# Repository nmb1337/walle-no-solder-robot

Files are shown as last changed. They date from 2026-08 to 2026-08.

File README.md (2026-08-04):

# WALL-E no-solder robot gateway

An A1-sized, PETG-printed WALL-E-style robot with two differential-drive
wheels, six positional joints, ESP32-S3 camera/audio hardware, and a Windows
LAN gateway for API-based text and image intelligence.

This is an original parameterised chassis. It is visually inspired by WALL-E
and studies of public community projects, but it does not redistribute or copy
another creator's STL files.

## Read these first

1. [Design dimensions and strict fit rules](DESIGN_FREEZE.md)
2. [No-solder bill of materials](docs/BOM.md)
3. [Assembly guide](docs/ASSEMBLY.md)
4. [Engineering validation and release gates](docs/VALIDATION.md)
5. [PETG / AMS Lite setup](shopping/ams-lite-setup.md)

The project is intentionally blocked from full-shell printing until the five
fit parts pass with the bought hardware. This prevents a wrong wheel bore,
battery pack, motor shaft or camera connector from turning into a large failed
print.

## Software

Run the local gateway with `start-gateway.ps1`. It serves the dashboard on
`http://127.0.0.1:8100` and exposes API-compatible text, image, motion, camera
and optional STT/TTS routes. API keys stay only in `gateway-config.json`, which
is not included in the project package.

The motor ESP32 polls the gateway for movement and joint events. It has a
one-second motor watchdog and starts stopped. See `firmware/README.md` before
connecting any battery.

## Print source

The source is `cad/walle_parametric.scad`; rendered V2 parts are in
`cad/stl_v2/`. Every V2 STL has been checked against the Bambu Lab A1
`256 x 256 x 256 mm` build volume. Print PETG fit parts first, then proceed in
the order in `docs/ASSEMBLY.md`.

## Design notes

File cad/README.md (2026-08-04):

# WALL-E v2 printable parts

`walle_parametric.scad` is the source of truth for the no-solder v2 design.
It targets a two-wheel, WALL-E-style robot built around bought 42 mm rubber
wheels, N20 motors, MG90S servos, a Waveshare ESP32-S3-AUDIO-Board and an
OV2640 camera board.

The current V2 exports are in `stl_v2/`. Every part stays below the Bambu A1
`256 x 256 x 256 mm` build volume. The previous `stl/` directory and its
CoreS3 tray are superseded and must not be sent to print.

## First fit prints

1. `walle_n20_motor_clamp.stl` x2
2. `walle_battery_tray.stl` x1
3. `walle_audio_core_cradle.stl` x1
4. `walle_ov2640_camera_mount.stl` x1
5. `walle_mg90s_horn_adapter.stl` x6
6. `walle_ball_caster_plate.stl` x1
7. `walle_base_plate.stl` x1

Use PETG at 0.20 mm layer height, 4 walls, and 30% gyroid infill for structural
parts. Print the body, head and cosmetic track covers only after these parts
fit the bought hardware. Full dimensions and strict buying rules are in
`../DESIGN_FREEZE.md`; use `../docs/ASSEMBLY.md` and
`../docs/VALIDATION.md` for the assembly and release gates.

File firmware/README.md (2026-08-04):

# Motion controller

`esp32_walle_controller.ino` runs on the pre-soldered ESP32 DevKitC V4. It
polls the Windows gateway every 250 ms, drives a TB6612FNG motor driver and a
PCA9685 servo board, and stops both motors after one second without a command.

## Exact connections

| ESP32 pin | TB6612FNG |
| --- | --- |
| GPIO 25 | AIN1 |
| GPIO 26 | AIN2 |
| GPIO 27 | PWMA |
| GPIO 32 | BIN1 |
| GPIO 33 | BIN2 |
| GPIO 14 | PWMB |
| GPIO 13 | STBY |
| 3.3 V | VCC |
| GND | GND |

PCA9685: ESP32 `GPIO 21 -> SDA`, `GPIO 22 -> SCL`, common GND, and a separate
regulated `5 V / 8 A or higher` rail on its servo power terminal. Motors use
the protected 2S battery at `VM`; the ESP32 and PCA9685 must share GND with
that battery but never draw servo current through the ESP32 USB port.

The sketch supports Arduino-ESP32 2.x and 3.x LEDC APIs. Gateway events use
ASCII values (`left`, `right`, `center`, `up`, `down`, `raise`, `stow`) so the
firmware is not affected by serial or source-file Chinese encoding.

Before fitting wheels or arms, power the controller from USB, verify all six
servo directions, then test each motor with the robot raised off the table.

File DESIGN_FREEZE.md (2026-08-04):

# WALL-E v2 design freeze

This is a no-solder, two-wheel WALL-E-style robot. It is intentionally not a
copy of the MakerWorld model. The MakerWorld page attributes its design to
other work under CC BY-NC-SA and its current print profile is not public, so
this project only uses it as visual and assembly reference.

## Mechanical envelope

All dimensions are millimetres. The source of truth is
`cad/walle_parametric.scad`.

| Printed / bought item | Frozen dimensions | Fit rule |
| --- | --- | --- |
| Base plate | 178 x 112 x 5 | Four M3 holes and battery straps |
| Body shell | 184 x 118 x 100 | Upper opening for service |
| Head shell | 182 x 90 x 76 | Front panel is removable |
| Face panel | 174 x 5 x 70 | Two 40 mm eye openings |
| Complete body, wheels included | about 240 wide x 118 deep x 184 high | Fits the A1 in separate parts |
| Drive wheels, bought | 42 diameter x 19 wide | 3 mm D-bore only, not round bore |
| N20 motor | 10 x 12 x 34-36 body, 3 mm D shaft, 6 V, 100 RPM | Must be pre-wired with a 2-pin connector |
| Motor clamp cavity | 38.5 x 13.4 x 11.4 | Cable tie slots; do not substitute a 25GA/370 motor |
| Battery tray internal envelope | 82 x 48 x 24 | Real pack must be no larger than 80 x 46 x 22 |
| MG90S servo envelope | 22.8 x 12.2 x 28.5 | Six 180-degree metal-gear units |
| ESP32-S3 audio board | 58 mm round board | 0.8 mm clearance in the printed cradle |
| OV2640 camera board | 35.7 x 23.9 | 24-pin 0.5 mm FPC version for the audio board |

The outer decorative side covers make the two-wheel chassis look like WALL-E
tracks. They are not load-bearing tracks. This is deliberate: two purchased
rubber wheels are quieter, easier to assemble, and reliable on tile and wood.

## Buy exactly these specifications

1. `Waveshare ESP32-S3-AUDIO-Board`, standard version, with dual microphone
   array, speaker header and 24-pin DVP camera connector. Do not buy an
   ESP32-S3-WROOM module alone: it needs soldering and has no ready audio path.
2. Compatible `OV2640 Camera Board`, `35.7 x 23.9 mm`, 24-pin, 0.5 mm FPC.
3. `ESP32 DevKitC V4`, USB-C and pre-soldered headers, for motors and servos.
4. Two `N20 6V 100 RPM` motors, `3 mm D shaft`, 10 x 12 x 34-36 mm. Buy the
   pre-wired 1.25 mm 2-pin version, plus one spare motor.
5. Two `42 x 19 mm` rubber robot wheels with a `3 mm D-bore`, not foam wheels
   and not a 2 mm or round bore wheel. This replaces TPU entirely.
6. `TB6612FNG` dual motor driver with pre-soldered signal header and screw
   terminals. It must have an accessible `STBY` pin.
7. `PCA9685` 16-channel servo board with pre-soldered headers.
8. Seven `MG90S 180-degree metal-gear` servos: six fitted, one spare. SG90,
   360-degree servos and 2 g aircraft servos are not compatible with this
   articulated design.
9. Protected `2S 7.4 V` Li-ion pack, maximum `80 x 46 x 22 mm`, with XT30
   output and an 8.4 V charger explicitly sold for that pack. Do not buy a
   18650 holder or a bare 18650 pack.
10. Fixed `5 V 10 A` buck converter with screw terminals for servos, ESP32
    DevKitC and the audio board. A 3 A converter is unsafe for six MG90S servos.
11. Fixed `6.0 V / 3 A` buck converter with screw terminals for TB6612 `VM`
    and the N20 motors. Do not connect a 2S battery directly to 6 V motors.
12. XT30 pre-made pigtail, 5 A inline fuse holder, 5 A fuse, 20 cm pre-crimped
    Dupont leads, and an M3 screw/standoff box. No stripping or soldering is
    required if every cable is bought pre-made.

The Taobao candidate [42 mm solid rubber N20 wheel](https://item.taobao.com/item.htm?id=657052441273)
does explicitly state `42 mm`, N20 compatibility and a `3 mm D-bore`. Its
page does not state wheel width, so ask the seller to confirm `19 mm or less`
before adding it to the cart. Do not substitute a different wheel just because
its title also says "N20".

## PETG and AMS Lite

Use PETG for every printed structural part. Do not put TPU in the AMS Lite.
If you have two PETG colours, load yellow in A and black in B. If you only
have one PETG spool, load it in A and print all parts in that material; colour
does not affect fitting. The bought rubber wheels provide grip.

Print and dry-fit before any large shell:

1. `cad/stl_v2/walle_n20_motor_clamp.stl`
2. One bought wheel and the motor shaft
3. `cad/stl_v2/walle_battery_tray.stl` with the real battery
4. `cad/stl_v2/walle_audio_core_cradle.stl` with the real ESP32-S3 board
5. `cad/stl_v2/walle_ov2640_camera_mount.stl` with the camera and FPC cable

The body and head are printed only after those five dry-fits pass. Also dry-fit
the MG90S horn adapter and rear ball-caster plate. The battery tray, motor
clamp, caster plate and horn adapter must be re-exported if a seller changes a
quoted physical dimension.

## Functional boundary

The gateway supports provider switching, text chat, image analysis, movement
and the standard OpenAI-compatible STT/TTS routes. The hardware is designed
for head yaw/pitch, two arms with shoulder/elbow joints, and two-wheel
movement. AI requests stay on the configured API, not on the 8100T.

Music playback must use a service and account that authorises playback. The
project will not promise access to an arbitrary percentage of copyrighted
catalogues or bypass a platform's controls.

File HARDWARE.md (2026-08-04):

# Hardware overview

Use [docs/BOM.md](docs/BOM.md) for the complete procurement specification and
[docs/ASSEMBLY.md](docs/ASSEMBLY.md) for the no-solder harness order.

The architecture has two controllers:

- ESP32 DevKitC V4 -> TB6612FNG -> two 6 V N20 motors and PCA9685 -> six
  MG90S 180-degree servos.
- Waveshare ESP32-S3-AUDIO-Board + OV2640 + 4 ohm speaker -> Wi-Fi voice and
  camera client for the Windows gateway.

Power starts at a fused 2S LiPo XT30 output. It splits into a `6.0 V / 3 A`
motor rail and an isolated `5 V / 10 A` servo/logic rail, with all grounds
common. The ESP32-S3 audio board receives the 5 V logic rail through USB-C.
No 6 V motor rail may enter an ESP32, PCA9685 logic pin or servo connector.

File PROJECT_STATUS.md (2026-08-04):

# Project status

## Completed

- Windows gateway with API profile storage that excludes secrets from source.
- Text and image relay support, dashboard movement controls and a one-second
  motion watchdog in the ESP32 controller.
- Original V2 OpenSCAD source and A1-bounded STL exports.
- No-solder BOM, PETG print guide, assembly guide and engineering validation.
- Static checks: gateway Python syntax, action translation, and V2 STL bounds.

## Required before full build

- Seller confirms motor shaft, wheel width/bore, battery dimensions and motor
  stall current against `docs/BOM.md`.
- Fit prints pass with real motor, wheel, battery, audio board, camera,
  supplied servo horn and ball caster.
- Regulated rails measure exactly 5.0 V and 6.0 V before electronics connect.
- Bench-test motors, six servos, watchdog, camera upload and API image call.

No purchase, order, payment, or printer job is submitted by this repository.

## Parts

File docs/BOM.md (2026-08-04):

# No-solder BOM

Buy by the **specification column**, not only by the title. A listing with a
different shaft, plug, voltage, or physical size is not a compatible
substitute. Prices change often, so this list intentionally avoids promising
one seller or one price.

## Motion and structure

| Qty | Exact specification | Maximum envelope / interface | Search words |
| --- | --- | --- | --- |
| 3 | N20 metal gearmotor, 6 V, 100 RPM, 3 mm D shaft, 10 x 12 x 34-36 mm | Stall current <= 0.8 A; pre-wired MX1.25 2P lead; two fitted + one spare | `N20 6V 100转 3mm D轴 带线 1.25` |
| 2 | Solid rubber wheel, 42 mm OD, <= 19 mm width, 3 mm D-bore | No foam, no round bore, no 2 mm shaft version | `42mm 橡胶实心轮 N20 3mm D孔` |
| 7 | MG90S metal-gear, 180 degree servo | 22.8 x 12.2 x 28.5 mm; six fitted + one spare | `MG90S 金属齿 180度` |
| 1 | 15 mm ball caster, complete assembly | body <= 20 x 20 x 16 mm; M2 mounting pattern must be shown | `15mm 万向滚球 小车` |
| 1 | M2 screw/nut kit | M2 x 6 and M2 x 8 for supplied servo horns | `M2 螺丝螺母盒` |
| 1 | M3 screw/standoff kit | M3 x 8/10/12/14/16 and M3 nuts | `M3 铜柱螺丝盒` |

## Electronics

| Qty | Exact specification | Required detail-page evidence | Search words |
| --- | --- | --- | --- |
| 1 | Waveshare ESP32-S3-AUDIO-Board, standard board | 58 mm round board; dual microphones, 24-pin DVP camera connector, speaker header | `微雪 ESP32-S3 AUDIO Board` |
| 1 | OV2640 camera board, 24-pin, 0.5 mm FPC | 35.7 x 23.9 mm; connector orientation matches the audio board | `OV2640 24P 0.5mm FPC 微雪` |
| 1 | 4 ohm / 3 W speaker with pre-crimped 1.25 mm 2P plug | 40 mm maximum diameter, connector already fitted | `4欧3W 喇叭 1.25 2P 带线` |
| 1 | ESP32 DevKitC V4 | USB-C and pre-soldered headers | `ESP32 DevKitC V4 已焊排针 Type-C` |
| 1 | TB6612FNG motor-driver board | pre-soldered signal header, screw terminals, STBY exposed | `TB6612FNG 端子 已焊排针` |
| 1 | PCA9685 16-channel servo board | pre-soldered header and separate servo power terminal | `PCA9685 已焊排针 舵机板` |
| 1 | USB-A to USB-C power lead | 20-30 cm, rated 3 A or above | `USB A 转 Type C 20cm 3A` |

## Power and pre-made wiring

| Qty | Exact specification | Why it is required |
| --- | --- | --- |
| 1 | 2S 7.4 V, 1500 mAh or higher, >= 20C LiPo soft pack, XT30 output, <= 80 x 46 x 22 mm | Fits the printed tray and supplies the simultaneous servo/motor peak. |
| 1 | Matched 2S balance charger for that pack | Never charge a 2S LiPo from a 5 V USB charger. |
| 1 | 5 V / 10 A fixed buck converter, screw terminals | Feeds PCA9685 servo rail, ESP32 DevKitC and the audio board through USB-C. 3 A is not sufficient. |
| 1 | 6.0 V / 3 A fixed buck converter, screw terminals | Feeds only TB6612 `VM` and the two N20 motors. A 2S pack must not be connected directly to 6 V motors. |
| 1 | XT30 pre-made pigtail to stripped/tinned wire, 20 cm | Connects the battery to the fused power split without soldering. |
| 1 | 5 A inline automotive-style fuse holder and 5 A fuse | In series with battery positive before both buck converters. |
| 1 | Pre-crimped Dupont kit, 20 cm, male-to-female and female-to-female | For ESP32, PCA9685 and TB6612 signals. |
| 1 | WAGO 221-412 lever connectors, or a small screw-terminal power distribution block | Makes the battery/buck ground common without soldering. |

## Do not buy

- CoreS3, standalone ESP32-S3-WROOM modules, bare PCBs, or boards requiring
  header soldering.
- SG90 continuous rotation servos, 2 g aircraft servos, or MG90S 360-degree
  versions. They cannot position the head and arms.
- 18650 holders, unprotected loose cells, a 3 A 5 V buck, or an N20 motor
  marked 300 RPM or 12 V.
- TPU filament. The purchased rubber wheels are the correct tyre material.

## Seller confirmation message

Send this exact question to a seller when a dimension is not on the page:

> 请确认这款 N20 电机为 6V、100RPM、3mm D 型输出轴，电机本体 10x12mm、总长 34-36mm、轴长至少 9mm，并且堵转电流不超过 0.8A。请确认轮子外径 42mm、宽度不超过 19mm、孔为 3mm D 孔。请提供实物尺寸图。

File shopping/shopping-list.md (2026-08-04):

# Purchasing status

The old CoreS3, 70 mm wheel, PLA and 5 V / 3 A shopping list is obsolete. Do
not add or purchase from it.

The authoritative no-solder purchase list, exact dimensions, quantity, search
words and seller-confirmation message are in [../docs/BOM.md](../docs/BOM.md).
The V2 design needs two separate regulated rails: `5 V / 10 A` for servos and
logic, and `6.0 V / 3 A` for the 6 V N20 motors.

The Taobao cart is intentionally not treated as verified. Before any item is
added, compare its product page with `docs/BOM.md`, especially the wheel bore
and width, motor stall current, real battery dimensions and all pre-crimped
connectors.

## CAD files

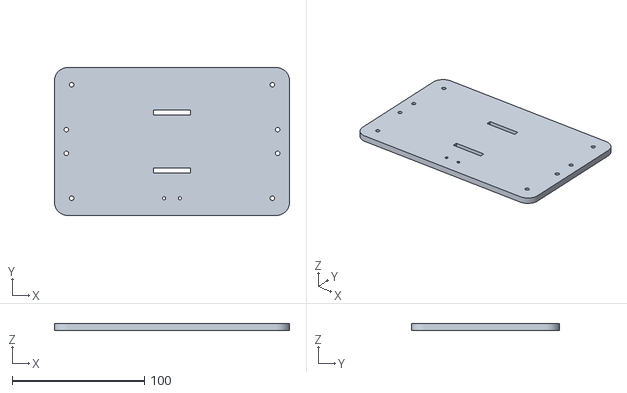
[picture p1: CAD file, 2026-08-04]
cad/stl_v2/walle_base_plate.stl
178.0 x 112.0 x 5.00

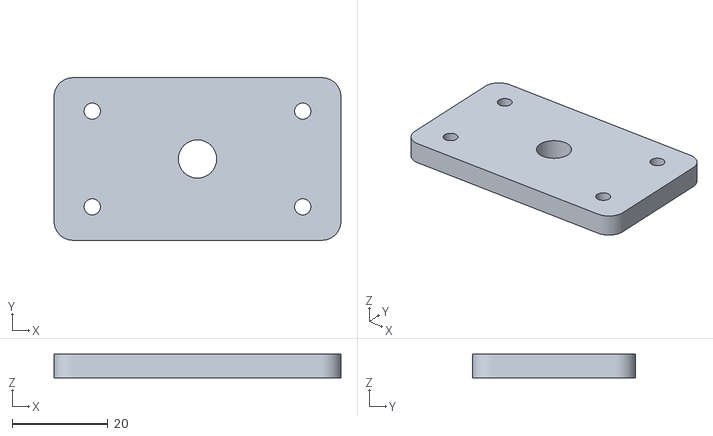
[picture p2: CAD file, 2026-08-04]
cad/stl_v2/walle_head_servo_adapter.stl
60.0 x 34.0 x 5.00

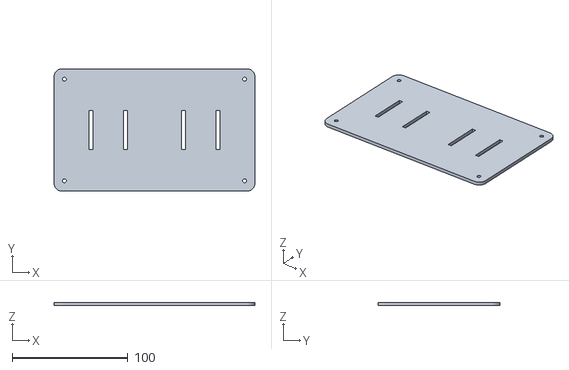
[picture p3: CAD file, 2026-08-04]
cad/stl_v2/walle_electronics_deck.stl
174.0 x 106.0 x 3.00

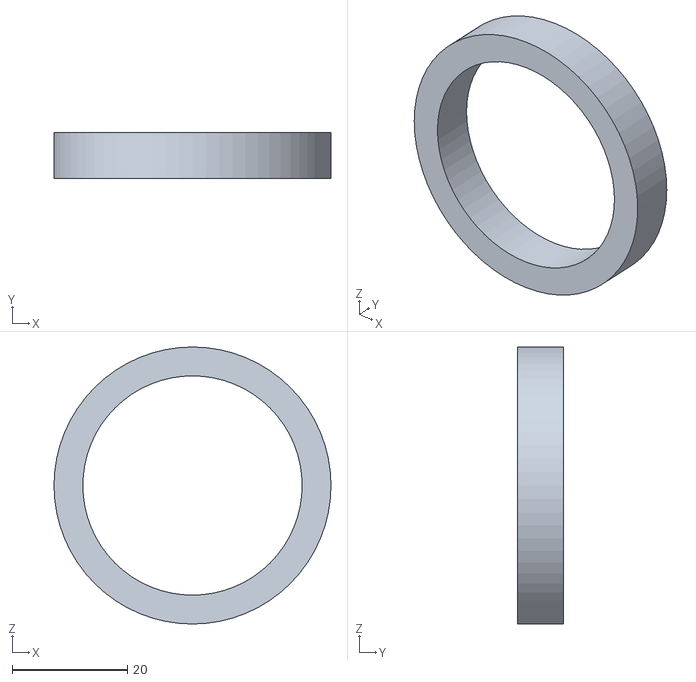
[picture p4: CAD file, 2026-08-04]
cad/stl_v2/walle_eye_ring.stl
48.0 x 8.00 x 48.0

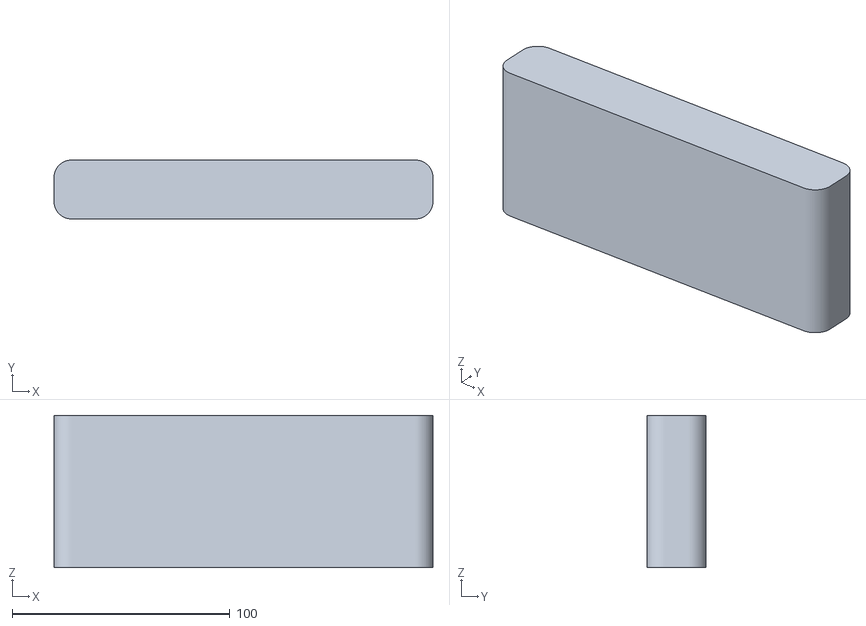
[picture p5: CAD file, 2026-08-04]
cad/stl_v2/walle_face_plate.stl
174.0 x 27.0 x 70.0

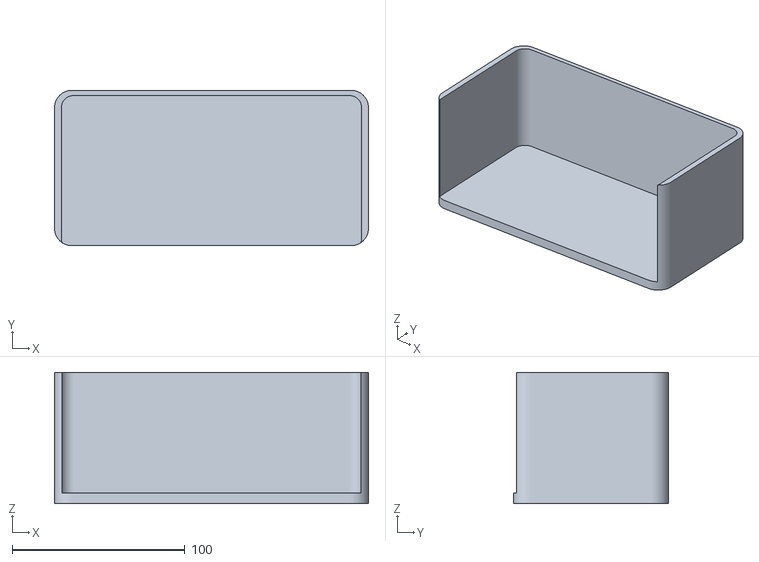
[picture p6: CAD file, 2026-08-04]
cad/stl_v2/walle_head_shell.stl
182.0 x 90.0 x 76.0

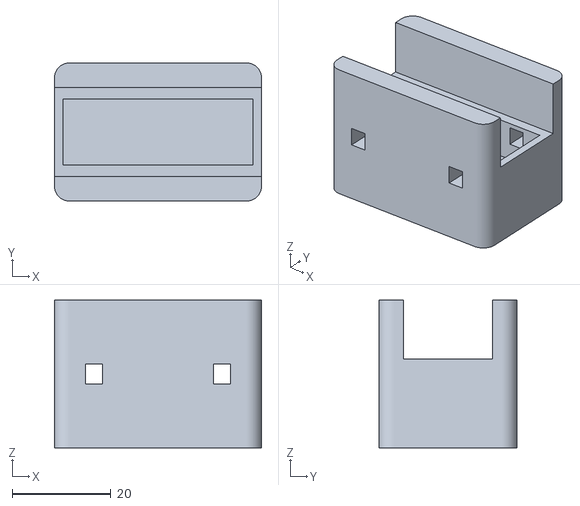
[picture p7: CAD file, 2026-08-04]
cad/stl_v2/walle_n20_motor_clamp.stl
42.0 x 28.0 x 30.0

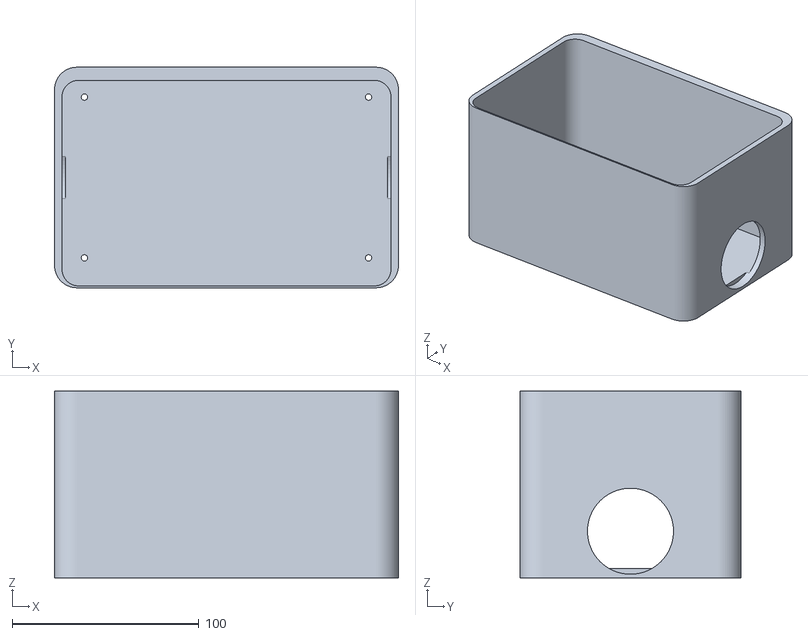
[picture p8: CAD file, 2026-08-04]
cad/stl_v2/walle_body_shell.stl
184.0 x 118.0 x 100.0

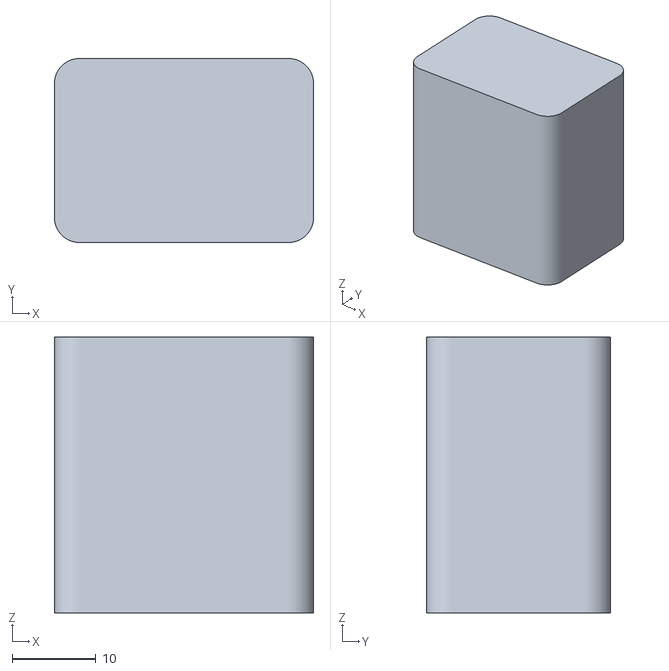
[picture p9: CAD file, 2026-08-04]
cad/stl_v2/walle_mg90s_servo_cradle.stl
31.0 x 22.0 x 33.0

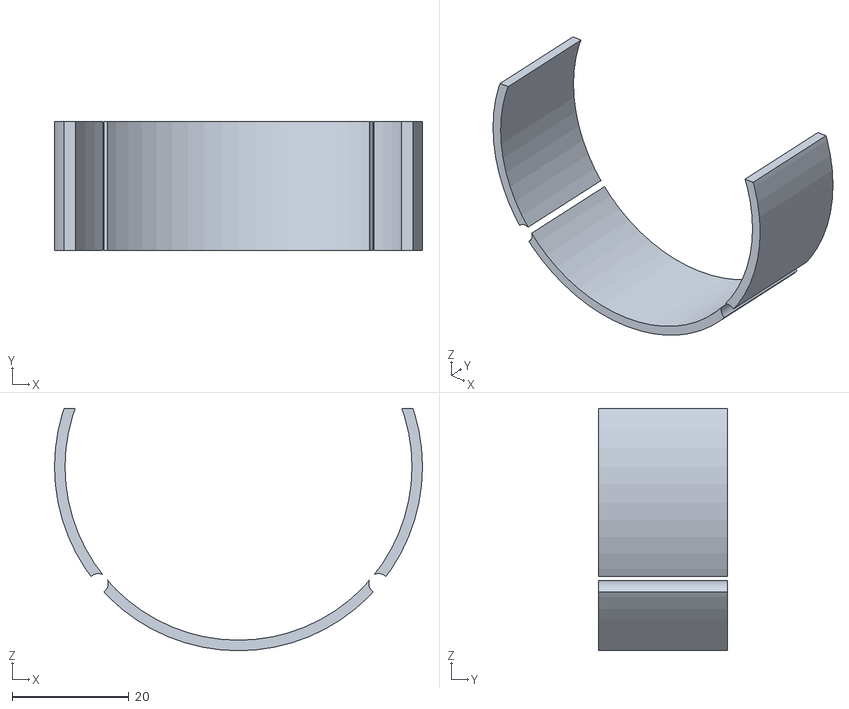
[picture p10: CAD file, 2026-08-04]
cad/stl_v2/walle_audio_core_cradle.stl
63.0 x 22.0 x 41.5

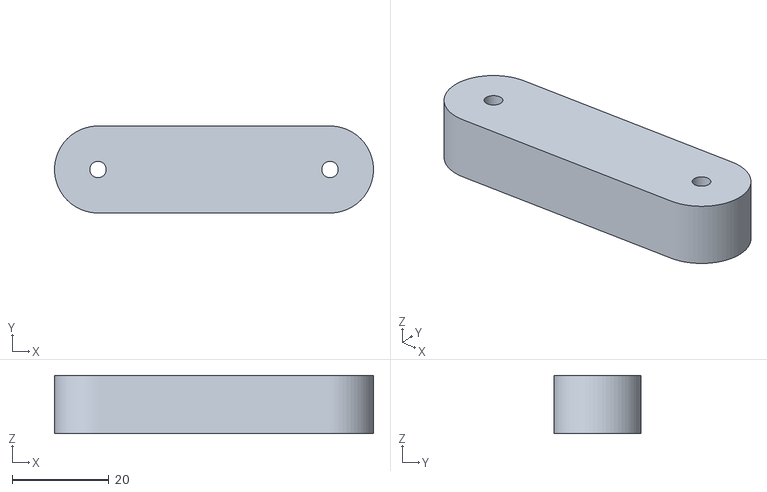
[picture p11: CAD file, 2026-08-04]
cad/stl_v2/walle_arm_link_upper.stl
66.0 x 18.0 x 12.0

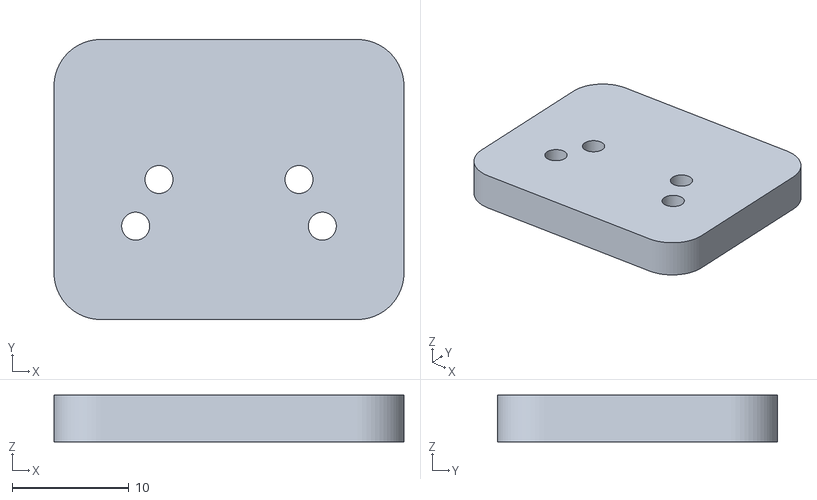
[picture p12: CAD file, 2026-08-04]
cad/stl_v2/walle_ball_caster_plate.stl
30.0 x 24.0 x 4.00

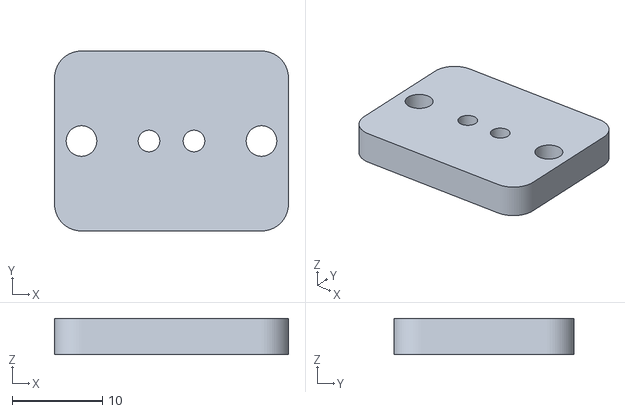
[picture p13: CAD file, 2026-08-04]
cad/stl_v2/walle_mg90s_horn_adapter.stl
26.0 x 20.0 x 4.00

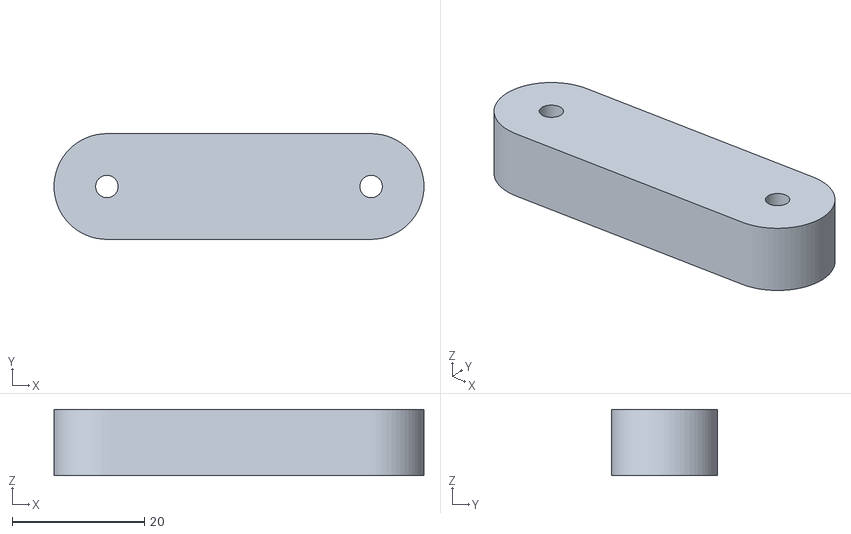
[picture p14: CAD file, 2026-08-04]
cad/stl_v2/walle_arm_link_lower.stl
56.0 x 16.0 x 10.0

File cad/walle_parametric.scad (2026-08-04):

// WALLE no-solder medium robot, millimetres.
// Target hardware: 42 mm N20 rubber wheels, MG90S 180-degree servos,
// Waveshare ESP32-S3-AUDIO-Board (diameter 58 mm, height 48.8 mm),
// and a 24-pin OV2640 camera module. Every printed part fits a Bambu A1.

$fn = 64;

body_w = 184;
body_d = 118;
body_h = 100;
head_w = 182;
head_d = 90;
head_h = 76;
wall = 3;
clearance = 0.8;

drive_wheel_d = 42;
drive_wheel_w = 19;
drive_axle_d = 3;               // N20 3 mm D-shaft
wheel_center_z = drive_wheel_d / 2 + 4;

mg90s_w = 22.8;
mg90s_d = 12.2;
mg90s_h = 28.5;

audio_core_d = 58;
audio_core_h = 48.8;
camera_pcb_w = 35.7;            // Waveshare OV2640 Camera Board
camera_pcb_h = 23.9;            // 24-pin, 0.5 mm FPC connector

// 2S 1800 mAh pack envelope. Smaller packs use foam and hook-and-loop strap.
battery_bay_w = 82;
battery_bay_d = 48;
battery_bay_h = 24;

part = "assembly_preview";

module rounded_box(w, d, h, r = 8) {
    linear_extrude(height = h, center = true)
        hull()
            for (x = [-w / 2 + r, w / 2 - r])
                for (y = [-d / 2 + r, d / 2 - r])
                    translate([x, y]) circle(r = r);
}

module m3_hole(h = 20) { cylinder(d = 3.4, h = h, center = true); }
module m2_hole(h = 20) { cylinder(d = 2.4, h = h, center = true); }

module base_plate() {
    difference() {
        rounded_box(178, 112, 5, 10);
        for (x = [-76, 76], y = [-43, 43])
            translate([x, y, 0]) m3_hole();
        // N20 motor-clamp pairs. Clamp centres are x = +/-80, y = 0.
        for (x = [-80, 80], y = [-9, 9])
            translate([x, y, 0]) m3_hole();
        // Rear ball-caster plate. M2 slots allow small seller variations.
        for (x = [-6, 6])
            translate([x, -43, 0]) m2_hole();
        // Hook-and-loop slots for battery and cable restraint.
        for (y = [-22, 22])
            translate([0, y, 0]) cube([28, 4, 10], center = true);
    }
}

module body_shell() {
    difference() {
        translate([0, 0, body_h / 2]) rounded_box(body_w, body_d, body_h, 12);
        // Open top, 6 mm bottom, 4 mm rear wall. Electronics insert from above.
        translate([0, -3, body_h / 2 + 5]) rounded_box(body_w - 8, body_d - 8, body_h, 9);
        // Clearance for two real 42 mm rubber wheels.
        for (side = [-1, 1])
            translate([side * (body_w / 2 + 2), 0, wheel_center_z])
                rotate([0, 90, 0]) cylinder(d = drive_wheel_d + 4, h = 16, center = true);
        // Match the base plate's four M3 body-fastening holes.
        for (x = [-76, 76], y = [-43, 43])
            translate([x, y, 3]) m3_hole(16);
    }
}

// Cosmetic side cover: it creates the WALL-E tracked appearance while the
// bought rubber wheel remains exposed through the 46 mm opening.
module track_cover() {
    difference() {
        rotate([0, 90, 0])
            linear_extrude(height = 5, center = true)
                difference() {
                    hull() {
                        translate([0, -32]) circle(d = 58);
                        translate([0, 32]) circle(d = 58);
                    }
                    circle(d = drive_wheel_d + 4);
                }
        // Two M3 mounting holes along the long axis.
        for (y = [-43, 43])
            translate([0, y, 0]) rotate([0, 90, 0]) m3_hole(12);
    }
}

module n20_motor_clamp() {
    difference() {
        rounded_box(42, 28, 30, 3);
        // N20 motor body and gearbox, axis along X. Use two small cable ties.
        cube([38.5, 13.4, 11.4], center = true);
        translate([0, 0, 9]) cube([44, 18, 12], center = true);
        for (x = [-13, 13])
            translate([x, 0, 0]) cube([3.5, 32, 4], center = true);
        for (y = [-9, 9])
            translate([0, y, -10]) m3_hole(8);
    }
}

module battery_tray() {
    difference() {
        rounded_box(battery_bay_w + 8, battery_bay_d + 8, battery_bay_h + 6, 5);
        translate([0, 0, 3]) rounded_box(battery_bay_w, battery_bay_d, battery_bay_h + 8, 3);
        for (y = [-15, 15])
            translate([0, y, 0]) cube([32, 4, 40], center = true);
    }
}

module electronics_deck() {
    difference() {
        rounded_box(174, 106, 3, 7);
        for (x = [-78, 78], y = [-44, 44])
            translate([x, y, 0]) m3_hole();
        // Universal tie-down slots instead of vendor-specific hole patterns.
        for (x = [-55, -25, 25, 55])
            translate([x, 0, 0]) cube([3.5, 34, 10], center = true);
    }
}

module head_shell() {
    difference() {
        translate([0, 0, head_h / 2]) rounded_box(head_w, head_d, head_h, 10);
        // Face is a separate panel; this leaves the front open for service.
        translate([0, -3, head_h / 2 + 3]) rounded_box(head_w - 8, head_d, head_h - 6, 7);
    }
}

module face_plate() {
    difference() {
        translate([0, 0, 36]) rounded_box(174, 5, 70, 8);
        for (x = [-44, 44])
            translate([x, 0, 43]) rotate([90, 0, 0]) cylinder(d = 40, h = 12, center = true);
        // Speaker grille: three rows of 4 mm holes below the eyes.
        for (x = [-24 : 8 : 24], z = [10 : 8 : 26])
            translate([x, 0, z]) rotate([90, 0, 0]) cylinder(d = 4, h = 12, center = true);
        for (x = [-76, 76])
            translate([x, 0, 8]) rotate([90, 0, 0]) m3_hole(12);
    }
}

module eye_ring() {
    difference() {
        rotate([90, 0, 0]) cylinder(d = 48, h = 8, center = true);
        rotate([90, 0, 0]) cylinder(d = 38, h = 12, center = true);
    }
}

// Holds the 35.7 x 23.9 mm OV2640 board behind one eye. It deliberately has
// generous clearance for the 24-pin FPC cable and works with a small foam pad.
module ov2640_camera_mount() {
    difference() {
        rounded_box(46, 8, 34, 3);
        cube([camera_pcb_w + 1.2, 12, camera_pcb_h + 1.2], center = true);
        rotate([90, 0, 0]) cylinder(d = 12, h = 14, center = true);
        for (x = [-18, 18])
            translate([x, 0, -12]) rotate([90, 0, 0]) m3_hole(14);
    }
}

// Cradle for Waveshare ESP32-S3-AUDIO-Board: official envelope is 58 mm x 48.8 mm.
module audio_core_cradle() {
    difference() {
        rotate([90, 0, 0]) cylinder(d = audio_core_d + 5, h = 22, center = true);
        rotate([90, 0, 0]) cylinder(d = audio_core_d + 1.4, h = 26, center = true);
        // Open the upper third so the board can be inserted without force.
        translate([0, 0, 25]) cube([80, 30, 30], center = true);
        for (x = [-24, 24])
            translate([x, 0, -20]) rotate([90, 0, 0]) m3_hole(30);
    }
}

module mg90s_servo_cradle() {
    difference() {
        rounded_box(31, 22, 33, 3);
        translate([0, 0, 1]) cube([mg90s_w + 0.9, mg90s_d + 0.9, mg90s_h + 1], center = true);
        for (x = [-12, 12])
            translate([x, 0, -12]) m3_hole(8);
    }
}

module shoulder_mount() {
    difference() {
        rounded_box(40, 30, 38, 4);
        translate([0, 0, 1]) cube([mg90s_w + 1, mg90s_d + 1, mg90s_h + 2], center = true);
        rotate([90, 0, 0]) cylinder(d = 8, h = 40, center = true);
        for (x = [-15, 15]) translate([x, 0, -14]) m3_hole(10);
    }
}

module arm_link_upper() {
    difference() {
        hull() {
            translate([-24, 0, 0]) cylinder(d = 18, h = 12, center = true);
            translate([24, 0, 0]) cylinder(d = 18, h = 12, center = true);
        }
        for (x = [-24, 24]) translate([x, 0, 0]) cylinder(d = 3.4, h = 20, center = true);
    }
}

module arm_link_lower() {
    difference() {
        hull() {
            translate([-20, 0, 0]) cylinder(d = 16, h = 10, center = true);
            translate([20, 0, 0]) cylinder(d = 16, h = 10, center = true);
        }
        for (x = [-20, 20]) translate([x, 0, 0]) cylinder(d = 3.4, h = 18, center = true);
    }
}

module head_servo_adapter() {
    difference() {
        rounded_box(60, 34, 5, 4);
        for (x = [-22, 22], y = [-10, 10]) translate([x, y, 0]) m3_hole();
        rotate([0, 0, 0]) cylinder(d = 8, h = 12, center = true);
    }
}

// Uses the supplied MG90S cross horn. The two central M2 holes match the
// short arm of the common 9 g servo horn; the outer M3 holes join the printed
// arm/head link. Confirm the supplied horn hole pitch during the first dry fit.
module mg90s_horn_adapter() {
    difference() {
        rounded_box(26, 20, 4, 3);
        for (x = [-2.5, 2.5]) translate([x, 0, 0]) m2_hole(10);
        for (x = [-10, 10]) translate([x, 0, 0]) m3_hole(10);
    }
}

// Flat adapter below the base plate for a bought <=20 x 20 x 16 mm ball
// caster. Its M2 slots accept a 12 mm nominal mounting pitch.
module ball_caster_plate() {
    difference() {
        rounded_box(30, 24, 4, 4);
        for (x = [-6, 6]) translate([x, 0, 0]) m2_hole(10);
        for (x = [-8, 8]) translate([x, -4, 0]) m2_hole(10);
    }
}
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

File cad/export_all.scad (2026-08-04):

// Export one part at a time with:
// openscad.com -o output.stl -D part=\"base_plate\" export_all.scad
include <walle_parametric.scad>;

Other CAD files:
cad/stl_v2/walle_ov2640_camera_mount.stl
cad/stl_v2/walle_shoulder_mount.stl
cad/stl_v2/walle_track_cover.stl
cad/stl_v2/walle_battery_tray.stl

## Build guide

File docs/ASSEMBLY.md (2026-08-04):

# No-solder assembly guide

Do not start with the body shell. Build in the order below and stop whenever a
fit check fails. The battery is connected only during the final electrical
test.

## 1. Print and measure the fit set

Print the V2 parts in PETG, 0.20 mm layer height, four walls and 30% gyroid:

1. `walle_n20_motor_clamp.stl` x2
2. `walle_battery_tray.stl` x1
3. `walle_audio_core_cradle.stl` x1
4. `walle_ov2640_camera_mount.stl` x1
5. `walle_mg90s_servo_cradle.stl` x2 and `walle_shoulder_mount.stl` x2
6. `walle_mg90s_horn_adapter.stl` x6 and `walle_ball_caster_plate.stl` x1
7. `walle_base_plate.stl` x1

Verify with calipers: N20 body must enter the clamp without force; the battery
must have at least 1 mm free space on each side; the audio board must sit in
its cradle with the USB-C and FPC connector accessible. A failed fit means
change the CAD parameter, re-export only that part, and repeat.

## 2. Prepare the mechanical subassemblies

1. Insert each MG90S into its printed cradle with the output shaft facing the
   printed arm/head adapter. Do not tighten the horn-centre screw yet.
2. Connect the supplied servo cross horn to its servo using the supplied centre
   screw. Attach the printed arm adapter to the horn with M2 x 6 screws and M2
   nuts; never drill the servo shaft or glue a horn permanently.
3. Bolt the base plate to the body with four M3 x 14 screws. The body floor
   and base mounting holes must be aligned before electronics are installed.
4. Put each N20 clamp on the base's outer M3 pair: clamp centres are
   `x = -80 mm` and `x = +80 mm`, with the two holes `18 mm` apart along Y.
   Use M3 x 10 screws and lock nuts. Fit the rubber wheels after the motors.
   Each wheel must be fully seated on the 3 mm D shaft, turn freely by hand,
   and not rub the PETG side cover.
5. Fit the rear ball caster last. With the robot on a flat table, both drive
   wheels and the caster must touch the surface; the body/base must be at
   least 3 mm above the table.

## 3. Make the power harness with pre-made parts

1. Battery XT30 positive -> 5 A fuse -> lever/screw-terminal distribution.
2. Distribution -> 5 V / 10 A buck input and 6 V / 3 A buck input.
3. 5 V buck -> PCA9685 servo power terminal, ESP32 DevKitC 5 V/VIN, and the
   ESP32-S3 audio board through its USB-C lead.
4. 6 V buck -> TB6612 `VM` and `GND` only.
5. Join every ground: battery, both buck converters, TB6612, ESP32, PCA9685
   and audio board. Do not connect the 6 V motor rail to any ESP32 pin.

Leave the battery unplugged until the multimeter check in the next section.

## 4. Signal wiring and bench test

Use the pin map in `firmware/README.md`. Power only from USB initially.

1. Upload the motor-controller firmware after filling Wi-Fi name, Wi-Fi
   password and the gateway LAN address.
2. With wheels off the ground, issue `forward`, `back`, `left`, `right`, then
   `stop` from the web UI. The one-second watchdog must stop both motors.
3. Power PCA9685 from the 5 V buck and test every servo independently before
   attaching the head/arms. Adjust the neutral angle in firmware only after
   confirming the safe physical range.
4. Connect the OV2640 FPC cable with power off. Then install the ESP32-S3
   audio board, speaker and USB-C power lead. Take one camera snapshot before
   enabling automatic screenshots.

## 5. Close the robot only after these tests pass

Install the electronic deck, secure wires with reusable cable ties, then fit
the head, arms, face panel and track covers. Keep the battery accessible and
do not pinch the camera FPC or speaker lead.

For real audio, configure an authorised STT/TTS API profile in the gateway.
The robot never stores API keys in either ESP32 firmware.

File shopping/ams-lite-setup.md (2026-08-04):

# AMS Lite PETG setup

No TPU is required. Grip comes from purchased rubber wheels, so there is no
TPU spool, TPU slicing profile, or AMS TPU feed in this project.

- A: yellow PETG for the body, head, arms, face panel and eye rings.
- B: black PETG for the base, motor clamps, electronic deck and side covers.
- If you only own one PETG colour, load it in A and print every part with it.

For fit parts, use 0.20 mm layer height, 4 walls, 30% gyroid infill and the
PETG manufacturer's normal A1 temperature profile. Structural fit prints
must be cooled and measured before using them as a template for the rest of
the shell.

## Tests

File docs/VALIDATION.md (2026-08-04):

# Engineering validation

## Verified by source and generated STL

| Check | Result | Evidence |
| --- | --- | --- |
| A1 build volume | Pass | All V2 STLs are <= 256 mm; largest body is 184 x 118 x 100 mm. |
| Battery cavity | Conditional | Tray inner envelope is 82 x 48 x 24 mm; buy pack <= 80 x 46 x 22 mm. |
| Motor-clamp mounting | Pass by coordinate | Base pairs at x = +/-80, y = +/-9 match the N20 clamp's 18 mm M3 pattern. |
| Camera | Pass by envelope | Mount cavity is 36.9 x 25.1 mm for a 35.7 x 23.9 mm board. |
| Audio board | Pass by envelope | Cradle has 0.8 mm radial assembly allowance for the 58 mm board. |
| Servos | Conditional | MG90S envelope is modelled. Horn adapter and real horn alignment need a dry fit. |
| Motor driver | Conditional | TB6612 is valid only when N20 stall current is <= 0.8 A. |
| Power | Pass after correction | Separate 6 V motor and 5 V / 10 A servo rails prevent N20 over-voltage and servo brownout. |
| Drive stability | Conditional | A rear 15 mm ball caster is mandatory; do not run a two-contact-point chassis. |

## Required physical gates

The CAD cannot prove a seller's unlabelled shaft length, wheel width, battery
dimensions, or servo horn moulding. The project is therefore **not cleared for
full-shell printing** until these gates are checked:

1. Seller supplies N20 and wheel size drawings matching `docs/BOM.md`.
2. First motor clamp, wheel, battery tray, camera mount and audio cradle pass
   a no-force dry fit.
3. The mounted base clears the floor by at least 3 mm on all three contact
   points.
4. Measured buck outputs are 5.0 V and 6.0 V before connecting electronics.
5. All six servos sweep their intended range without an arm/head collision.
6. The motor watchdog stops the wheels after a one-second command loss.

Only after all six gates pass may the body, head and cosmetic covers be sent to
the A1. This is the boundary between a dimensionally reviewed design and a
physically validated robot.

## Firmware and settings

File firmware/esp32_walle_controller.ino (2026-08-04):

// WALLE controller for ESP32 DevKitC + TB6612FNG + PCA9685.
// Install libraries: ArduinoJson 6 and Adafruit PWM Servo Driver Library.
// Keep motor battery and 5V logic rails separate, with a common ground.
#include <WiFi.h>
#include <HTTPClient.h>
#include <ArduinoJson.h>
#include <Wire.h>
#include <Adafruit_PWMServoDriver.h>

const char* WIFI_SSID = "CHANGE_ME";
const char* WIFI_PASSWORD = "CHANGE_ME";
const char* GATEWAY = "http://192.168.1.20:8100";

// TB6612FNG: AIN1/AIN2/PWMA, BIN1/BIN2/PWMB, STBY.
const int AIN1=25, AIN2=26, PWMA=27;
const int BIN1=32, BIN2=33, PWMB=14, STBY=13;
const int PWMA_CHANNEL = 0, PWMB_CHANNEL = 1;
Adafruit_PWMServoDriver pwm(0x40);
const int servoChannels[6] = {0,1,2,3,4,5};
unsigned long lastCommandMs = 0;
unsigned long lastPollMs = 0;
long lastEventId = 0;

// Arduino-ESP32 2.x addresses LEDC by channel; 3.x addresses it by pin.
// Keep one source compatible with both commonly shipped ESP32 board packages.
void setupMotorPwm() {
#if ESP_ARDUINO_VERSION_MAJOR >= 3
  ledcAttachChannel(PWMA, 20000, 8, PWMA_CHANNEL);
  ledcAttachChannel(PWMB, 20000, 8, PWMB_CHANNEL);
#else
  ledcSetup(PWMA_CHANNEL, 20000, 8); ledcAttachPin(PWMA, PWMA_CHANNEL);
  ledcSetup(PWMB_CHANNEL, 20000, 8); ledcAttachPin(PWMB, PWMB_CHANNEL);
#endif
}

void writeMotorPwm(int pin, int channel, int duty) {
  duty = constrain(duty, 0, 255);
#if ESP_ARDUINO_VERSION_MAJOR >= 3
  ledcWrite(pin, duty);
#else
  ledcWrite(channel, duty);
#endif
}

void motor(int in1, int in2, int pwmChannel, int speed) {
  digitalWrite(in1, speed > 0); digitalWrite(in2, speed < 0);
  writeMotorPwm(pwmChannel == PWMA_CHANNEL ? PWMA : PWMB, pwmChannel, abs(speed));
}
void stopMotors() { motor(AIN1,AIN2,PWMA_CHANNEL,0); motor(BIN1,BIN2,PWMB_CHANNEL,0); digitalWrite(STBY, LOW); }
void moveAction(const char* action) {
  const int speed = 150;
  digitalWrite(STBY, HIGH);
  if (!strcmp(action,"forward")) { motor(AIN1,AIN2,PWMA_CHANNEL,speed); motor(BIN1,BIN2,PWMB_CHANNEL,speed); }
  else if (!strcmp(action,"back")) { motor(AIN1,AIN2,PWMA_CHANNEL,-speed); motor(BIN1,BIN2,PWMB_CHANNEL,-speed); }
  else if (!strcmp(action,"left")) { motor(AIN1,AIN2,PWMA_CHANNEL,-speed); motor(BIN1,BIN2,PWMB_CHANNEL,speed); }
  else if (!strcmp(action,"right")) { motor(AIN1,AIN2,PWMA_CHANNEL,speed); motor(BIN1,BIN2,PWMB_CHANNEL,-speed); }
  else { stopMotors(); }
  lastCommandMs = millis();
}
void setServoAngle(uint8_t channel, int angle) {
  angle = constrain(angle, 10, 170);
  int pulse = map(angle, 0, 180, 150, 600);
  pwm.setPWM(channel, 0, pulse);
}
void applyEvent(JsonObject event) {
  JsonObject payload = event["payload"];
  const char* kind = event["kind"] | "";
  if (!strcmp(kind,"move")) moveAction(payload["action"] | "stop");
  if (!strcmp(kind,"action")) {
    const char* head = payload["head"] | "";
    const char* arm = payload["arm"] | "";
    if (!strcmp(head,"left")) setServoAngle(servoChannels[0], 55);
    if (!strcmp(head,"center")) setServoAngle(servoChannels[0], 90);
    if (!strcmp(head,"right")) setServoAngle(servoChannels[0], 125);
    if (!strcmp(head,"up")) setServoAngle(servoChannels[1], 65);
    if (!strcmp(head,"down")) setServoAngle(servoChannels[1], 118);
    if (!strcmp(head,"center")) setServoAngle(servoChannels[1], 90);
    if (!strcmp(arm,"raise")) { setServoAngle(servoChannels[2], 125); setServoAngle(servoChannels[3], 75); setServoAngle(servoChannels[4], 55); setServoAngle(servoChannels[5], 105); }
    if (!strcmp(arm,"stow")) { setServoAngle(servoChannels[2], 70); setServoAngle(servoChannels[3], 110); setServoAngle(servoChannels[4], 110); setServoAngle(servoChannels[5], 70); }
  }
}
void pollEvents() {
  HTTPClient http; http.begin(String(GATEWAY) + "/api/events");
  int code = http.GET();
  if (code == 200) {
    DynamicJsonDocument doc(8192);
    if (!deserializeJson(doc, http.getString())) {
      for (JsonObject event : doc["events"].as<JsonArray>()) {
        long id = event["id"] | 0;
        if (id > lastEventId) { applyEvent(event); lastEventId = id; }
      }
    }
  }
  http.end();
}
void setup() {
  pinMode(AIN1,OUTPUT); pinMode(AIN2,OUTPUT); pinMode(BIN1,OUTPUT); pinMode(BIN2,OUTPUT); pinMode(STBY,OUTPUT);
  setupMotorPwm(); stopMotors();
  Wire.begin(); pwm.begin(); pwm.setOscillatorFrequency(27000000); pwm.setPWMFreq(50);
  for (int ch : servoChannels) setServoAngle(ch, 90);
  WiFi.begin(WIFI_SSID, WIFI_PASSWORD);
  while (WiFi.status() != WL_CONNECTED) delay(300);
  lastCommandMs = millis();
}
void loop() {
  if (millis() - lastPollMs > 250 && WiFi.status() == WL_CONNECTED) { lastPollMs = millis(); pollEvents(); }
  if (millis() - lastCommandMs > 1000) stopMotors();
  delay(10);
}

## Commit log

2026-08-04 Add validated no-solder WALL-E build package
    [export_all.scad, walle_arm_link_lower.stl, walle_arm_link_upper.stl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]
2026-08-04 Add matched N20 base mounting pattern
    [walle_base_plate.stl, walle_parametric.scad]
